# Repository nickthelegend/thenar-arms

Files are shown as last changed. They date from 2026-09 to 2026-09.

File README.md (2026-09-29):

# Thenar Arms

An original-derived SO-101 project with two separate builds: a six-MG996R
positional-servo **follower** and a passive, six-AS5600 **encoder leader**. The
repository includes converted STL parts, Bambu P1S geometry layouts, articulated
SolidWorks assemblies, a browser-based 3D viewer, an assembly animation, and
prototype ESP32 firmware.

> **Prototype status:** CAD and software checks are documented, but the complete
> printed mechanism, purchased hardware, wiring, and powered motion have **not**
> been physically validated. There is no payload rating or print-ready G-code.

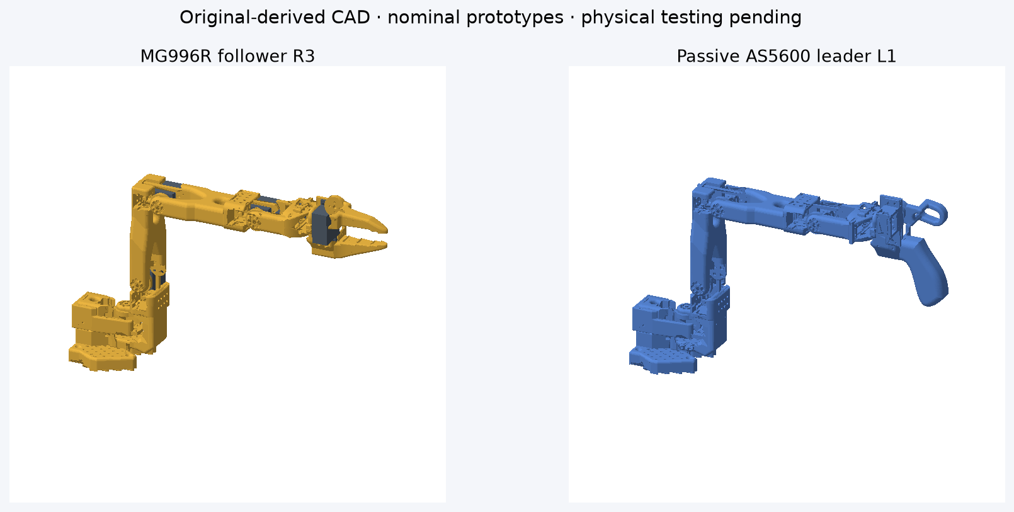
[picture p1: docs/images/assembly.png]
MG996R follower and encoder leader CAD assemblies


## Start here

| What you want | Link |
|---|---|
| Inspect both arms in 3D | [Open Robot Studio](https://nickthelegend.github.io/thenar-arms/) |
| See where each part goes | [Interactive 3D assembly film](https://nickthelegend.github.io/thenar-arms/assembly-video.html) — drag the timeline or pause at a step |
| Watch offline | [180-second MP4](robot-studio/public/video/thenar-real-3d-assembly-180s.mp4) |
| Build the MG996R follower | [Follower BOM, print notes and assembly](so101-mg996r/R3-PRINT.md) |
| Build the encoder leader | [Leader BOM, print notes, wiring and calibration](so101-mg996r/ENCODER-LEADER.md) |
| Use a Raspberry Pi 4B as host | [Pi 4B wiring and bridge guide](so101-mg996r/RASPBERRY-PI-4B.md) |
| Use only one ESP32 | [Pi-direct follower wiring guide](so101-mg996r/RASPBERRY-PI-DIRECT-FOLLOWER.md) and [large-print 90-second connection video](https://nickthelegend.github.io/thenar-arms/wiring-video.html) |

The one-ESP32 layout uses the ESP32 for leader sensing and Pi I²C for the
PCA9685. **The current bridge still needs a second ESP32**; a Pi-side follower
driver and physical electrical testing are not yet complete. The video is an
illustrated connector guide, not footage of the purchased boards.

The assembly animation uses project STL meshes and nominal CAD positions. Individual
fasteners and unspecified controller boards are not modeled. It is an assembly
guide, **not** proof that parts fit, move safely, or work electrically.

## Choose a build

| | MG996R follower R3 | Passive encoder leader L1 |
|---|---|---|
| Actuation / sensing | Six 180° positional MG996R servos; no external follower encoders | Six passive AS5600 angle-sensing joints; no drive servos |
| Print set | 7 joined units, 2 P1S geometry-only layouts | 37 pieces from 12 unique STLs, 3 P1S geometry-only layouts |
| Essential hardware | 6 matching 25T metal-disc horns, ESP32, PCA9685, separate regulated 6 V servo supply, mounting fasteners | 6 Adafruit 6357 AS5600 boards, 12 **688ZZ 8 × 16 × 5 mm** bearings, 6 diametric Ø6 × 2 mm magnets, ESP32, TCA9548A, fasteners |
| Files | [Follower STL/3MF ZIP](so101-mg996r/output/follower-r3/SO101-MG996R-R3-PROTOTYPE.zip) | [Leader STL/3MF/firmware ZIP](so101-mg996r/output/encoder-leader-l1/SO101-AS5600-LEADER-L1.zip) |
| Detailed guide | [R3-PRINT.md](so101-mg996r/R3-PRINT.md) | [ENCODER-LEADER.md](so101-mg996r/ENCODER-LEADER.md) |

These are **converted parts**, not the stock SO-101 Ender plates. Do not mix R3
follower brackets, L1 leader parts, earlier revisions, and untouched stock
parts. The original link shapes and source datums are retained; this is not a
whole-arm scale-up. Case, horn, bearing and board dimensions are nominal design
inputs, not measurements of the user's purchased components.

**Before a full print:** inspect every sliced layer in Bambu Studio, then
print and dry-fit one mount or one five-piece encoder cartridge. The 3MF files
are layouts, **not approved sliced projects**. The follower and leader guides
document unresolved slicer clipping/layer-review findings. PETG is the planned
structural material; a successful PLA test does not establish strength.

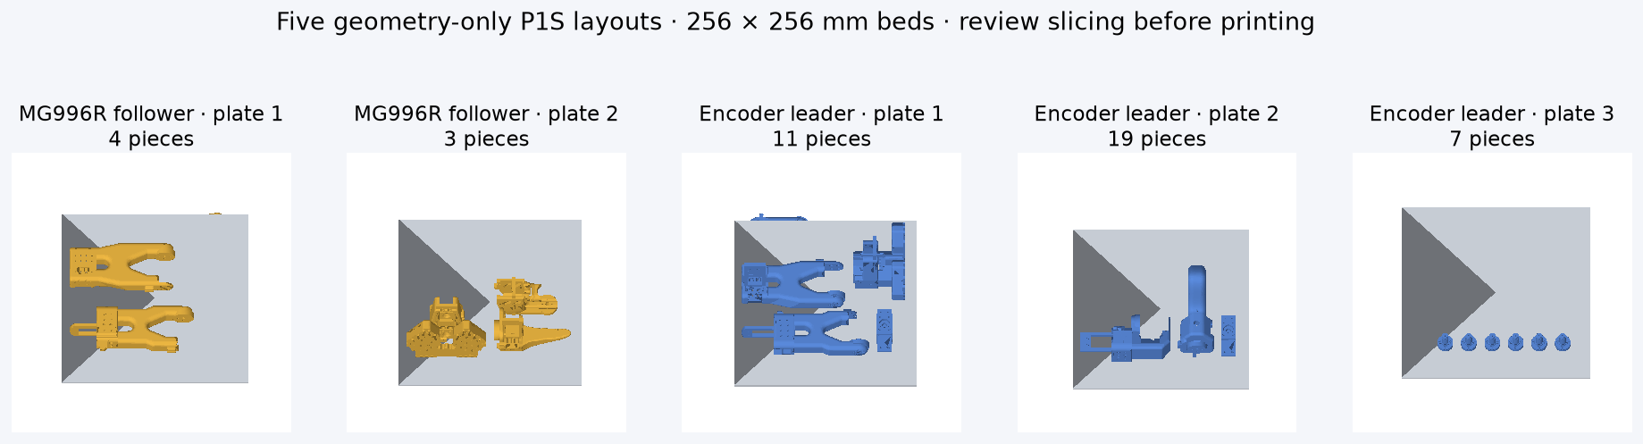
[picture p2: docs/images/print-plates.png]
P1S geometry layouts for the converted parts


## CAD, simulation and evidence

The [SolidWorks reconstruction release](https://github.com/nickthelegend/thenar-arms/releases/tag/solidworks-r3-l1-2026-09-23)
contains separate articulated follower and leader assemblies. Open the
[follower master](solidworks/assemblies/SO101_Follower_Master.SLDASM) or
[leader master](solidworks/assemblies/SO101_Leader_Master.SLDASM) with their
`solidworks/parts/` and `solidworks/hardware/` folders alongside them. See the
[SolidWorks guide](solidworks/README.md) and [reconstruction report](docs/final_report.md).

| Native assembly | Components | Moving joints | Recorded SolidWorks pose checks |
|---|---:|---:|---:|
| Follower R3 | 19 | 6, including jaw | 28/28 passed |
| Leader L1 | 73 | 6, including trigger | 28/28 passed |

The SolidWorks work did **not** modify the 330 existing project STL/3MF files;
those files do not need reprinting because of that reconstruction. Its CAD
solids are not byte-identical to the STLs. The reports document sampled surface
differences, a small leader-forearm solid-body separation, and collision
results. ROS 2 description and MuJoCo kinematics passed recorded pose checks;
ROS 2 visualization, Isaac import and physical dynamics were not tested.

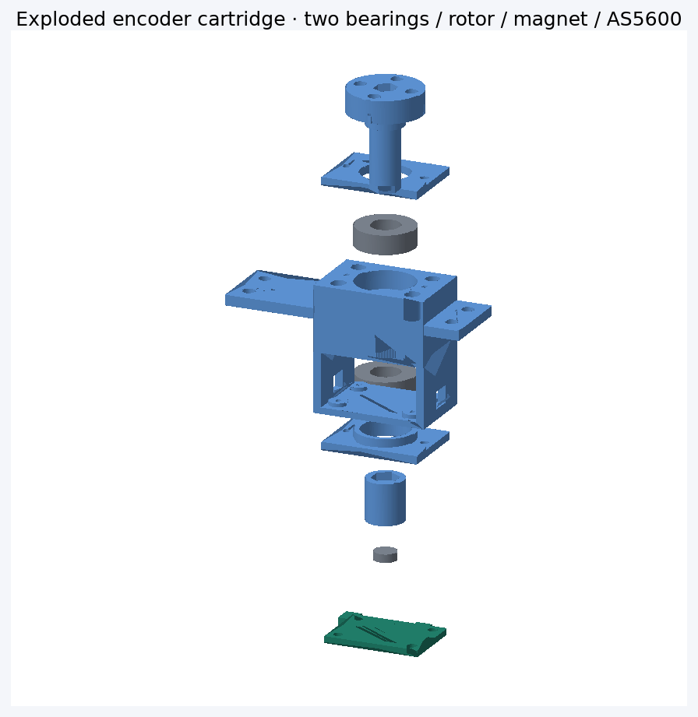
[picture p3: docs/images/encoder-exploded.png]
Exploded encoder cartridge CAD


### Validation boundaries

| Check | Recorded result |
|---|---|
| Closed single-shell print meshes | 7 follower + 12 unique leader meshes |
| Nominal mounting interfaces | 6/6 follower and 6/6 leader checks passed |
| Sampled internal collision poses | Follower 72/72 clear; leader 70/72 clear. Two folded leader collisions and table intersections remain documented. |
| Encoder cartridge | Sampled rotation/PCB checks show no positive overlap; magnet gap is nominally 2 mm. |
| P1S layouts | Five geometry layouts fit the P1S envelope with 12 mm part spacing. Slicing release is **not cleared**. |
| Firmware | Both ESP32 roles compile and host motion-math tests pass; follower stays locked until calibration. |
| Real hardware | **Not validated:** actual fits, bearings, sensors, wiring, strength, powered travel or payload. |

The browser preview checks discrete poses; it is not a swept-path or physical
safety certificate. The firmware STOP/OE path does not cut servo power. Clamp
and support the arm, and provide an accessible hardware power disconnect.
See the [encoder verification report](so101-mg996r/output/encoder-leader-l1/verification.json)
for machine-readable results.

## Run Robot Studio locally

```sh
cd robot-studio
npm ci
npm run dev
```

Open `http://127.0.0.1:5173/` for the arm viewer,
`http://127.0.0.1:5173/assembly-video.html` for the seekable 3D assembly
animation, or `http://127.0.0.1:5173/?geometry=clearance&view=fit-test` for
print-layout geometry. `?geometry=original` shows untouched upstream references.
The website does not connect to hardware.

<details>
<summary>Reproduce the current CAD and validation checks</summary>

Use a Python 3.12 environment with
[`so101-mg996r/requirements-cad.txt`](so101-mg996r/requirements-cad.txt)
installed, then run from the repository root:

```sh
python so101-mg996r/tools/build_encoder_leader.py
python so101-mg996r/tools/verify_encoder_leader.py
python so101-mg996r/tools/pack_encoder_leader.py
cd robot-studio
node scripts/verify-preview.mjs
node scripts/verify-r3.mjs
node scripts/verify-encoder.mjs
npm run build
```

Optional publishing/slicing scripts and firmware commands are in the kit
guides. No command here automatically flashes firmware or arms servos.

</details>

## Source and licences

The original SO-101 design is from
[TheRobotStudio/SO-ARM100](https://github.com/TheRobotStudio/SO-ARM100),
Apache-2.0; its licence is preserved at `so101-mg996r/source/LICENSE`.
The AS5600 board drawing is from
[Adafruit Industries](https://github.com/adafruit/Adafruit-AS5600-Magnetic-Angle-Sensor-PCB),
CC BY-SA, with attribution in `so101-mg996r/source/encoder/`.
Third-party assets keep their respective licences; this repository does not
relicense them. The images above are CAD renders, not photos of a tested robot.

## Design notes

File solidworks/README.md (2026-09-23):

# SolidWorks reconstruction

Engineering prototypes: not physically tested or payload rated. The existing R3 follower and L1 leader remain the geometric references; original CAD, print layouts, browser viewer and firmware were not redesigned.

Open `assemblies/SO101_Follower_Master.SLDASM` or `assemblies/SO101_Leader_Master.SLDASM` after their verification status is recorded in `../docs/final_report.md`. Keep the `parts/` and `hardware/` directories together with the assemblies so references resolve. Checkpoints and failed trials are retained separately and are not production substitutes.

The follower has 19 instances and six revolute joints, including the direct-drive moving jaw. The passive leader has 73 instances: 37 prints and 36 hardware envelopes, with six AS5600 sensing joints. Each assembly grounds only its base. Purchased envelopes, bearing caps and the source-surface patches use native features where practical. Most custom print geometry is retained as imported solid base features with native joint sketches, axes and planes; a fully editable manufacturing feature history has not been recovered.

## Move the joints

Use the ConfigurationManager to select **ZERO**, **HOME** or **MID_RANGE** for repeatable snapshots. These activate six optional pose-holding angle mates and suppress the redundant range mates. Select **FREE_MOTION** to suppress the holders and activate the six native Limit Angle mates, giving six bounded rotational freedoms. Select HOME before FREE_MOTION when you want to start from HOME. The named Mate Controller (`Follower_Joint_Poses` / `Leader_Joint_Poses`) operates the pose holders and stores individual minimum and maximum poses as well.

For scripted movement, use `tools/set_robot_pose.py follower 0 -25 35 0 0 20` (or `leader`) with the project Python environment. Add `--save` only to persist that pose. The task-local MCP tool `set_robot_joint_pose` accepts the same six logical degree values. It uses native mate solving, preserves all range properties and checks the resulting component transforms. Direct edits through the older API trial scripts can collapse limit bounds; use the supplied range-preserving helper.

In the Mates folder, `J1_Source_preview_limits` through `J6_Source_preview_limits` define the source ranges. `J1_Pose_driver` through `J6_Pose_driver` are the optional snapshot holders. They correspond to shoulder pan, shoulder lift, elbow flex, wrist flex, wrist roll and gripper/trigger. The native angle is **90 degrees + the logical joint angle**. Do not edit the configured minimum/maximum bounds when changing a pose. ZERO is [0,0,0,0,0,0]; HOME is [0,-25,35,0,0,20] degrees. MID_RANGE is [0,0,0,0,0,35].

API drag probes did not reliably preserve the entire follower assembly and were discarded. Free mouse dragging is unverified; use the configurations or native mate controls. The controlled pose tests do not certify collision-free physical movement. In particular, isolated J2_MAX and J3_MAX follower poses penetrate the tabletop.

## Geometry and frames

The source's native Z-up frame is retained. The viewer's side-by-side X placement is removed. The CAD scene includes the source +2.4 mm tabletop placement; the URDF robot base omits that scene placement. `simulation/cad_rig.json` records the explicit transformation. The `SOURCE_Z_UP` view changes only the camera, not robot coordinates.

The follower forearm has three solid partitions. The leader base and forearm each have four. The leader forearm requires a disclosed 0.00001 mm internal numerical separation. Source zero-thickness artifacts are retained as labelled native sheets on the leader trigger and forearm; no physical thickness is invented. These are geometric preservation choices, not physical manufacturing validation.

## Evidence and simulator handoffs

Read `../docs/final_report.md`, `../verification/original_vs_solidworks.md`, and the machine-readable evidence in `evidence/` and `../verification/`. The ROS 2 package is under `../ros2_ws/src/so101_description/`. MuJoCo and Isaac handoffs are under `../simulation/`.

Physical mass, center of mass, inertia, actuator/contact properties and calibration remain unverified. The MuJoCo structural template deliberately refuses to infer physical inertias. ROS 2 visualization and Isaac import have not been run in this environment.

The faceted CAD is memory intensive. Open one robot assembly at a time if memory is limited. Build tools checkpoint mates and clear their undo history; saved checkpoints provide recovery. The MCP bridge is task-local stdio tooling in `tools/solidworks_mcp.py`, with no network listener or persistent installation.

## Supported pose tools

Use `tools/set_robot_pose.py` or the MCP `set_robot_joint_pose` tool for normal movement. `validate_real_limits.py`, `verify_master_assembly.py` and `audit_native_mate_connections.py` are verification tools. Reconstruction and `probe_*` scripts include historical rejected trials; they are not normal movement commands. In particular, do not use `add_configuration_pose_drivers.py`, the old `validate_leader_motion.py`, or raw component-drag probes on the delivered masters.

The main report is `../docs/final_report.md`; `../verification/deliverable_files.json` indexes delivered files separately from checkpoints.

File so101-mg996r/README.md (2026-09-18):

# SO-101 original-geometry MG996R conversion work

## New: passive encoder leader L1

The original-derived leader conversion is now in `output/encoder-leader-l1`:
37 pieces on three P1S geometry layouts. See [ENCODER-LEADER.md](ENCODER-LEADER.md)
for the complete BOM, verified nominal interfaces, wiring, firmware and remaining
physical tests. The current viewer shows both converted assemblies. Full-plate
slicer clearance is still pending; these are not ready-to-run G-code files.

## Current: original-derived MG996R follower R3

The actual converted kit is now in `output/follower-r3/print-parts`: **seven
joined printing units**, derived from the original SO-101 parts. It has six
MG996R tab mounts, six metal-disc horn interfaces, joint-travel reliefs and an
8 mm local wrist extension. Use [R3-PRINT.md](R3-PRINT.md) for its current BOM,
dimensions and assembly notes. Do not mix R1/R2 parts or fasteners into this kit.

- Seven exported units are closed, positive-volume, single-shell meshes.
- All six nominal insertion and tab/horn screw-land checks pass.
- No internal overlaps above the report's threshold in 72 sampled poses;
  eight poses intersect the table and are guarded in the viewer.
- Two P1S geometry layouts hold all seven units with 12 mm part spacing.
- **Slicing review is still open:** both plates generated G-code, but clipping
  diagnostics and coarse toolpath-screen candidates remain. Ready-to-run sliced
  files are withheld. Full-plate printing is not approved by these checks.
- Physical fit, single-sided shaft support, strength, payload, cables and powered
  operation remain untested. Encoder leader L1 is supplied separately above.

The website defaults to this R3 follower. `?geometry=original` explicitly opens
the stock reference. `?geometry=clearance&view=fit-test` now shows the actual R3
layouts, not the earlier test-only or original SO-101 plates.

Download: [R3 prototype ZIP](output/follower-r3/SO101-MG996R-R3-PROTOTYPE.zip).
The sections below preserve earlier development results; they are **historical**
and do not describe the current R3 follower or its checks.

## Historical: printable MG996R bench-fit prototype R1

See [FIT-TEST.md](FIT-TEST.md) and [BOM.md](BOM.md). Actual original-derived
wrist-holder test STL/STEP and two small gauges are in `output/fit-test-r1`.
The holder adds mounting ledges, screw slots, nut access and an insertion opening.
It is one valid solid, with zero nominal servo overlap; all three test meshes
are watertight. This is separate from the incomplete full-arm study below.

P1S / 0.4 mm / PETG slicing passed: quick gauges approximately 18 minutes and
5 g; holder plus gauges approximately 1 hour 28 minutes and 24 g on one plate.
Print the quick gauges first. **Unpowered bench fit only; not a complete arm.**
The website's Print plates view now includes these test prints before the stock
SO-101 layouts. `?geometry=clearance&view=fit-test` opens them directly.

## Wrist-spacing development R2 — still not a print release

`output/wrist-spacing-r2` contains an editable original-derived wrist part with
an 8 mm local section extension. No global mesh scaling was used. With the roll
servo/gripper shifted accordingly, the two nominal wrist servo envelopes have
zero positive-volume interference in 81 pitch samples from -80° to +80° in 2°
steps; minimum sampled separation is approximately 2.566 mm. A 4 mm shift was
insufficient. This is a servo-pair test, NOT a complete assembly motion check.

The extension and clearance-cut STEP are each valid single solids, but the R2
STL still has open seams. An automatic repair was rejected because its volume
differed from the STEP by approximately 0.243%, exceeding the 0.1% repair gate.
R2 is intentionally not in the print-test ZIP or presented as printable. Flange,
horn, opposite-side support and surrounding-link checks remain incomplete.
The existing whole-arm report and viewer were not silently altered by this work.

## Historical initial study — NOT an MG996R print kit

All 14 requested individual STLs and both Ender combined layouts were downloaded
from TheRobotStudio/SO-ARM100 at commit
`eecbe3e0a9ebb23e25ad7b2759b03884c6660903`. They are byte-for-byte identical to
the same revision in the workspace. `source/provenance.json` records download
URLs, SHA-256 hashes, dimensions and mesh checks. Original files are unmodified.
The matching original STEP files are in `source/STEP`. Upstream Apache-2.0
licensing is preserved in `source/LICENSE`.

The website now renders these original shapes, not the earlier custom arm.
Follower joint frames come from the upstream URDF. The original leader handle
shares the wrist housing's mounting coordinates; its trigger pose is provisional.
Joint motion is a geometric preview, not a collision or hardware test.

## Historical initial verification and viewer update

The user has confirmed that the purchased servos only travel 180 degrees.
The MG996R preview now uses provisional ranges of ±85°, ±80°, ±80°, ±80°,
±85°, and 0–70° respectively. These are inspection limits, NOT mechanically
validated operating limits. The original-reference view retains upstream limits.
The two bases are separated by 800 mm for display only; no STL dimensions changed.

`output/motion-verification.json` records a 44-pose CAD check: home, neutral,
18 single-joint min/mid/max poses, 16 motion-demo samples and 8 seeded combined
poses. All 44 contain unresolved positive-volume overlaps in the nominal model.
There are seven home-pose candidates, including approximately 1,092 mm³ between
the unchanged wrist motor holder and the nominal MG996R envelope. Two draft
STLs still have open seams: Motor_holder_SO101_Base and Wrist_Roll_Pitch_SO101.
The check includes conservative circular horn envelopes, so the exact pair and
assumed hardware must be reviewed before deciding a repair. It does not certify
continuous swept motion, minimum clearance, leader encoders, strength or payload.

The website displays the report and lets you select its sampled poses. The
software tests verify that all twelve displayed joints move their attached
geometry, transforms remain finite, input is clamped, and the two display
assemblies do not overlap at home. These are software checks, not physical tests.

**Do not print the draft conversion as a finished arm.**

## Purchased servo — user-reported 180-degree travel

The user purchased a four-pack from
[Amazon ASIN B0F2TKPB95](https://www.amazon.in/dp/B0F2TKPB95).
The page was inspected on 2026-09-17. It identifies Generic / TESTIN ELECTRONICS,
not a verified TowerPro product. Its title advertises 180-degree operation, but
the description, included-components field and box contents describe a
360-degree continuous-rotation version. A verified buyer reports receiving
continuous-rotation servos. Those statements do NOT establish what the user
actually received; the page is internally inconsistent. The user's subsequent
confirmation of 180-degree travel is now recorded in `purchased-hardware.json`.

This distinction is essential: a positional servo accepts a target angle;
a continuous-rotation servo normally accepts speed/direction. Continuous-rotation
units cannot perform this arm's requested angle positioning without external
feedback or different servos. The user explicitly requested NO external arm
encoders, so adding them is not an approved workaround.

Before final calibration, test one servo off the robot with the horn
unloaded, using a servo tester and an appropriate separately powered supply.
Move the control slightly to either side of neutral: does the shaft move to a
new position and hold, or keep turning? Do not force the shaft by hand to test
travel. Do not power a servo from a microcontroller's GPIO or 3.3 V rail.
Stop if it stalls, overheats or behaves unexpectedly.

The listing's rounded 40 × 40 × 20 mm dimensions are not a machining drawing.
The supplied horn hole pattern, tab pitch and actual shaft datums remain
unmeasured. The fit study uses nominal MG996R geometry, NOT confirmed dimensions
of this Amazon product. Its nominal 20 mm metal horn is an assumption, not a
claim about the horn kits supplied with this purchase.

The follower needs six positional servos including the gripper. If only one
four-pack was purchased, two further matching units would eventually be needed;
confirm the existing units before buying any more.

## What was actually generated

- `source/Individual`: all 14 exact source STLs.
- `source/Follower` and `source/Leader`: both original Ender combined STLs.
- `source/STEP`: original editable solids, not reverse-engineered approximations.
- `output/manifest.json`: original-part assembly transforms for the viewer.
- `output/clearance-study`: localized subtractive fit-study STEP/STL exports,
  nominal MG996R reference mesh, and a per-part interference/removal report.

The fit study never scales or replaces the arm. It subtracts nominal servo,
horn and provisional cable-clearance envelopes at original joint locations.
It does NOT yet create a complete load-bearing attachment system. Some draft
tessellations have open seams; consult `fit-analysis.json`. These are inspection
artifacts, not print-ready parts. Watertightness alone would not establish
mechanical compatibility or strength.

The wrist motor holder clearance cut produces TWO separate solids and is
rejected. No converted wrist motor holder STL is exported. The wrist roll/pitch
part loses approximately 21.6% of its volume under the current assumptions,
which makes wall thickness and load paths especially important to review.

Four unaffected or leader-only files are preserved unchanged in the study
package. A draft suffix on them does not mean an encoder conversion was done.
The leader remains the original reference; AS5600 cartridges have not been
designed in this original-design branch.

## P1S layouts

The original Ender follower layout and original Ender leader layout each fit
inside a P1S 256 × 256 × 256 mm envelope after rigid translation only. Neither
the original orientations nor mesh scale is changed. Each layout occupies one
plate, with Y > 35 mm and X > 19 mm, clear of the front-left exclusion rectangle.
The website offers geometry-only 3MF layouts and the untouched combined STLs.

These are STOCK SO-101 plates, not MG996R plates. They are not sliced toolpaths.
No minimum-time claim, support approval, or MG996R print-time estimate is made.
Do not print them expecting the purchased MG996Rs to fit.

## Remaining engineering sequence

1. Calibrate the usable angle range and horn indexing of the reported 180-degree servos.
2. Measure body L/W/H, overall height, shaft offset, tab span/thickness/height,
   hole pitch and diameters, and the included horn hole pattern and stack height.
3. Register those measured datums to the original SO-101 joint axes.
4. Complete local tab mounts, horn attachment and opposite-side idler support;
   repair the rejected wrist mount while retaining the original design.
5. Check minimum walls, fastener access, cable bend paths and swept interference.
6. Evaluate direct-drive shoulder/elbow torque, current and heating. No payload
   is rated; published stall torque is not a continuous working torque.
7. Print and bench-test a single joint. Correct tolerances before full plates.
8. Fit passive encoder cartridges into the original leader housings.
9. Arrange only approved parts for P1S, slice, inspect supports and measure times.

The earlier `mg996r-arm` custom design and firmware are retained for history but
are NOT the authority for this requested original-design conversion. In
particular, its 2:1 transmission calibration must not be used for this branch.

## Reproduce

From the workspace root:

```sh
mg996r-arm/.venv/bin/python so101-mg996r/tools/import_sources.py
mg996r-arm/.venv/bin/python so101-mg996r/tools/clearance_study.py
mg996r-arm/.venv/bin/python so101-mg996r/tools/verify_motion.py
cd robot-studio
node scripts/verify-preview.mjs
npm run dev -- --host 127.0.0.1
```

The local site is normally at http://127.0.0.1:5173/.
Use its geometry selector for Original SO-101 versus MG996R clearance study.
Do not overwrite the source files with draft exports.

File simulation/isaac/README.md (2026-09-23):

# Isaac Sim import handoff

Import `source_urdf/so101.urdf` using the URDF importer in the installed Isaac Sim release. Relative mesh paths are self-contained. Follow `config/import_requirements.yaml`; compare the same joint vectors to `validation/canonical_pose_reference.json` in metres before accepting articulation.

Isaac Sim was unavailable in this task environment, so no import, USD or dynamics validation is claimed. `usd/` is intentionally empty. Missing physical inertials and unaccepted convex collision proxies block trustworthy physics. Do not accept automatic density, mass, drive gains or single-convex-hull approximations as measured robot data. Preserve the original dimensions and source joint limits.

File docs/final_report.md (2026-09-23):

# SO-101 SolidWorks reconstruction report

Engineering prototypes: **not physically tested or payload rated**. The current R3 six-MG996R follower and L1 passive six-AS5600 leader were reconstructed in SolidWorks 2026 SP4.1 through a task-local MCP bridge and the installed COM API. Original geometry, browser viewer, P1S layouts and firmware were preserved. All 330 original files match their saved hashes; see `verification/original_file_integrity.json`.

## Reconstruction

| Deliverable | Location | Instances / unique parts | Moving joints | Native mates / fixed components |
|---|---|---|---|---|
| Follower | `solidworks/assemblies/SO101_Follower_Master.SLDASM` | 19 / 9 | 5 arm + 1 jaw | 36 total; 30 active in FREE_MOTION / base only |
| Passive leader | `solidworks/assemblies/SO101_Leader_Master.SLDASM` | 73 / 18 | 5 arm + 1 trigger | 90 total; 84 active in FREE_MOTION / base only |

The leader comprises 37 printed instances and 36 hardware-envelope instances. Native feature hardware includes the MG996R envelope, metal horn, two bearing caps, PCB/chip/connectors, bearings and magnet. Custom printed geometry is mostly source-preserving imported solid base features with native datum sketches/axes/planes. This is **not** a recovered, fully parametric manufacturing feature history.

Final loaded references contain 11 follower solid bodies and 25 leader solid bodies across their unique parts. All return zero kernel faults. The leader additionally contains 11 healthy zero-thickness surface bodies preserving source artifacts. Native saved configuration checks pass with no reported mate errors. Only one root is grounded in each assembly.

Open one master at a time on a memory-limited workstation. Keep `solidworks/parts/` and `solidworks/hardware/` beside the assemblies. `solidworks/README.md` explains the controls and reference paths. Checkpoints and rejected trials are retained separately.

## Joint table

| Joint | Parent → child | Axis / positive sign | Zero; min…max (deg) | Servo channel / sensor mux | Motion |
|---|---|---|---|---|---|
| shoulder_pan | base_link → shoulder_link | local +Z / right-hand; default +1 | 0; -85…85 | 0 / 0 | Both CAD assemblies PASS |
| shoulder_lift | shoulder_link → upper_arm_link | local +Z / right-hand; default +1 | 0; -80…80 | 1 / 1 | Both CAD assemblies PASS |
| elbow_flex | upper_arm_link → lower_arm_link | local +Z / right-hand; default +1 | 0; -80…80 | 2 / 2 | Both CAD assemblies PASS |
| wrist_flex | lower_arm_link → wrist_link | local +Z / right-hand; default +1 | 0; -80…80 | 3 / 3 | Both CAD assemblies PASS |
| wrist_roll | wrist_link → gripper_link | local +Z / right-hand; default +1 | 0; -85…85 | 4 / 4 | Both CAD assemblies PASS |
| gripper | gripper_link → moving_jaw_so101_v1_link | local +Z / right-hand; default +1 | 0; 0…70 | 5 / 5 | Both CAD assemblies PASS |

Axes above are **local joint-frame +Z**, not all global vertical. Full measured origin XYZ/RPY and component mappings are in `simulation/joint_map.yaml` and `simulation/leader_joint_map.yaml`. Source frame: +X forward at HOME, +Y left, +Z up. Source viewer X separation is removed; CAD retains +2.4 mm tabletop placement. URDF base coordinates omit that scene placement; the explicit relation is in `simulation/cad_rig.json`.

ZERO = [0,0,0,0,0,0], HOME = [0,-25,35,0,0,20], MID_RANGE = [0,0,0,0,0,35] degrees. These are saved configurations. Native Mate Controllers also store 12 individual limit poses. Native mate angle = 90° + logical angle. The limits are **SOURCE VERIFIED software/preview bounds**, not measured safe mechanical stops. Do not command a physical robot merely because a pose is within these bounds.

The jaw and trigger are direct revolute DOFs; no additional coupled linkage was invented. Leader trigger mesh mounting index +15° is retained in its instance transform. Firmware leader ZERO capture is performed at HOME: q = home + sign × signed_wrap_12bit(raw − zero_counts) × 360/4096. Actual signs/count offsets and servo horn indexing remain UNVERIFIED.

## Accuracy

- **SOURCE VERIFIED:** source register and conflict decisions in `docs/source_audit.md`; modified R3/L1 geometry takes precedence over stock STEP files from a different revision. Detailed source dimensions, generator constants and original transforms were retained rather than averaged.
- **CAD MEASURED / CALCULATED:** follower printed surfaces compared using all vertices plus 30,000 samples per direction (50,000 for the partitioned forearm). Largest observed error: 0.001958407 mm. Base and wrist miss the stricter 0.001 mm trial, but all seven pass the source generator's 0.005 mm tolerance. This is sampled agreement, not mathematical identity.
- **CAD MEASURED / CALCULATED:** all 18 adopted leader part exports pass the recorded 0.005 mm surface, 0.001 mm bounds and per-type volume gates. Largest observed bidirectional surface discrepancy: 0.003381282 mm. Full values, stricter 1 µm outcomes and native-circle tessellation differences are in `verification/leader_geometry_comparison.json`.
- Follower forearm uses three valid solids in one rigid part. Leader base and forearm use four each. The leader forearm includes a disclosed 0.00001 mm internal numerical gap, approximately 0.0238 mm³ removed, to resolve coincident source facets rejected by the CAD kernel. Its zero-thickness source patch is preserved as eight surface facets; three trigger patches are likewise retained. No physical thickness was fabricated.
- Across 28 actual mate-solved poses, maximum follower component position/orientation difference is 2.66553607e-09 mm / 3.86653971e-10°. Leader maximum is 5.80356045e-07 mm / 3.86665823e-10°. Every component, including hardware, was compared to source forward kinematics.
- Hole/interface exteriors are included in the surface comparisons. Not every hole was reconstructed as an editable dimension. Unrepresented screws, cables and internal commercial-component details were not inferred into CAD.

## Motion validation

Every joint was exercised independently at minimum, zero, maximum and return; HOME and a combined pose were tested. Both assemblies pass all 28 recorded pose comparisons and the three saved-configuration reopen checks. Evidence is under `solidworks/evidence/`, plus `verification/follower_master_reopen.json`, `leader_master_reopen.json`, `joint_verification.csv` and `leader_joint_verification.csv`.

The final regression reads back all six genuine native Limit Angle feature types and their lower/upper bounds at every pose. Earlier fixed-angle and converted-mate trials are retained as superseded checkpoint evidence. The final limits were created with CreateMateData/CreateMate and explicit plane entities. Their current dimensions retain the default native driving state; making these dimensions driven caused the rejected bounds drift. Explicit joint-axis references prevent alternate angle solutions when configurations change. All six pose values are written explicitly per configuration, including unchanged values, to avoid stale inherited dimension state. Six separate optional angle holders make ZERO/HOME/MID_RANGE repeatable; these snapshots suppress the redundant range mates. FREE_MOTION suppresses the holders and activates all six limits. This avoids native redundant-mate warnings in the fixed snapshots. Only the base is fixed. Native component status with active limit mates is recorded separately and is not used as a numerical DOF count; suppression of a limit changes that diagnostic. The hinge graph and measured joint movement establish the reported articulation scope. Every native mate's actual component entities are audited against the source adjacency/rigid groups.

Constraint-matrix analysis gives six independent rotational freedoms and no additional infinitesimal freedoms at HOME for each native mate graph. This is **CALCULATED**, not a SolidWorks kernel DOF diagnostic or a mouse-drag test. Native mate-driven movement is separately CAD MEASURED.

Follower API drag probes and a leader direct-dimension solver-branch trial failed and were rejected. Saved masters were recovered/retested. Use named configurations and native mate controls; free mouse dragging remains UNVERIFIED. No accepted pose is produced by assigning arbitrary component transforms.

Discrete volumetric collision checks cover 15 named measured poses for each assembly (14 distinct joint vectors because J6_MIN equals ZERO), all component pairs, with no pair exclusion. Source zero-thickness leader sheets are retained in visual geometry but have no solid volume to intersect. Raw overlaps down to 0.00001 mm³ are recorded; 0.5 mm³ is the inherited source report threshold, not a physical clearance allowance. Follower native SolidWorks HOME interference independently confirms six intended servo shaft/horn engagements of about 9.032 mm³. No other follower sampled internal overlap exceeds 0.5 mm³; smaller fixed overlaps remain recorded.

- Follower `J2_MAX`: 10 components below table Z=0; lowest -193.784 mm.
- Follower `J3_MAX`: 3 components below table Z=0; lowest -73.187 mm.
- Leader `J2_MAX`: 37 components below table Z=0; lowest -203.582 mm.
- Leader `J3_MAX`: 9 components below table Z=0; lowest -82.985 mm.

The inherited L1 source report separately checks 72 poses, with two folded combined collision failures and 11 table-collision poses. Its cartridge checks cover 72 rotor samples, six interfaces and a source magnet-to-chip gap of 2 mm. Those are labelled source results; they are not substituted for current CAD measurements. Neither discrete set certifies swept motion, cables, physical fit or safe payload operation. Existing geometry was not redesigned to remove these limitations.

## Simulation and firmware

| Output | Status |
|---|---|
| `ros2_ws/src/so101_description/` | Xacro/XML, parser, connected tree (8 links/7 joints/6 moving), mesh paths/units and 28 pose regressions PASS. ROS 2 build/RViz not run; tooling was not found in the accessible environment. |
| `simulation/mujoco/so101_import_test.urdf` | MuJoCo 3.14.0 imports 6 joints; all 28 FK regressions PASS. Automatically inferred masses are explicitly rejected. No physical-dynamics stepping accepted. |
| `simulation/mujoco/so101.xml` | Structural MJCF template with inferred inertia disabled. Expected load rejection was tested. Requires real inertias and accepted contact geometry before dynamics. |
| `simulation/isaac/` | Self-contained validated URDF, meshes, importer requirements and pose references prepared. Isaac import/articulation/USD not tested; no USD fabricated. |
| `simulation/inertial_properties.yaml` | CAD unit-density geometric integrals and per-rigid-link contributions provided; physical mass, COM and inertia remain null/UNVERIFIED. |
| `so101-mg996r/firmware/joint_mapping.md` | Six PCA9685 channels 0–5 mapped to logical joints; ESP32 and leader AS5600/TCA9548A addresses, signs, HOME/zero and calibration relationships documented. Original firmware unchanged. |

Follower collision geometry uses source-envelope servo box/cylinder unions and exact CAD print/horn tessellation. Servo primitive union comparison passed (maximum sampled deviation 0.000324 mm). A fine convex print decomposition was rejected as impractically fragmented. Concave print meshes are retained for geometric inspection; validated convex dynamic-contact proxies are still outstanding. Simulators must not silently replace each concave print with one convex hull.

Firmware defaults are 1500 µs neutral, +1 sign, 5.555556 µs/degree, direct ratio 1:1. The 0.2° per 20 ms update ceiling is a 10°/s commanded slew, not a measured servo capability. No supported effort/payload rating is assigned.

## Unverified properties and next physical validation

1. Measure printed link/hardware masses, centers of mass and inertia or validate a defensible infill-aware model. Generic PETG, four walls and 25% gyroid do not justify uniform-solid mass. The plate filament total includes support/brim. Genuine TowerPro's 55 g reference is not confirmed for the user's generic units.
2. Check actual servo shaft/horn fit, bearing seats, fastener stack-ups, screw locations/retention and mounting tolerances. Some fasteners are listed in the source BOM but not spatially represented in the published assembly. Source zero-thickness patches and multipart seams need manufacturing review.
3. Measure mechanical stops and table/self-clearance over continuous motion, including cable routing and pinch regions. Software bounds are not verified physical limits.
4. Calibrate each servo neutral, sign, horn index, endpoint and backlash; each AS5600 zero count, direction, magnet alignment and usable sensing gap. Check the leader-to-follower mapping on a supported, power-limited prototype.
5. Measure torque/speed, friction, damping, compliance, contact behavior, power/current limits, thermal behavior and payload capacity. No values were invented to make a simulator run.
6. Validate free mouse dragging if desired. Named configurations and mate-definition controls are the tested CAD movement path.
7. Complete accepted convex contact proxies and run ROS 2 visualization, MuJoCo physical dynamics and Isaac articulation/USD validation when the required measured data/tooling are available.

## Evidence and reproducibility

The final task-local MCP command successfully set and saved HOME in both masters with all six native limits active and no mate errors. All 15 saved Mate Controller positions were then read back; see `solidworks/evidence/follower_mcp_pose_handoff.json`, `solidworks/evidence/leader_mcp_pose_handoff.json` and the two `*_final_controller_positions.json` files in that evidence directory. The follower is left open in its saved HOME configuration for handoff.

Five paired native SolidWorks and MuJoCo visual views (ZERO, J1_MAX, J2_MIN, MULTI and HOME) are in [the visual pose comparison](../verification/visual_pose_comparison.md). Their complete silhouettes and joint orientations were inspected after fitting each camera to its pose. Numerical component-transform regressions accompany the images; camera/shading differences are not treated as geometric errors.

`docs/source_audit.md`, `docs/decision_log.md`, `docs/open_issues.md`, `verification/original_vs_solidworks.md`, the two joint maps, raw pose/part evidence, and source hash manifest identify what is SOURCE VERIFIED, CAD MEASURED, CALCULATED or UNVERIFIED. The delivered-file index is `verification/deliverable_files.json`. Scripts are in `solidworks/tools/`; failed/rejected trials are explicitly separate from delivered masters. Do not rerun raw reconstruction scripts over accepted parts without first reading their checkpoint/adoption assumptions.

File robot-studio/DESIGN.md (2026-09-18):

# Robot inspection workspace

Mode: Operate. The user's instruction to build end to end settles the design workflow without a separate direction approval. Seven grounded directions considered: machining console, Onshape inspector, robotics lab notebook, precision product configurator, fabrication workbench, scientific instrument panel, museum exploded specimen. The fourth is the chosen direction: a light gray 3D inspection field, compact dark blue header, quiet component tree and precise joint controls. Amber identifies follower prints, blue identifies leader prints, graphite and metal identify purchased hardware. Measurements use tabular numerals. The CAD export is the visual centerpiece; there are no generated mock robot images. The cloud/quarry challengers do not serve an engineering inspection task; their whitespace discipline is retained. Mobile inspection preserves the viewport first and puts controls below it.

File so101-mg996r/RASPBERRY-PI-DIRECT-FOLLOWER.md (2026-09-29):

# One-ESP32 wiring: encoder leader → Pi 4B → MG996R follower

This is the **one-ESP32 alternative** requested for the Thenar arms. The ESP32 reads the six leader encoders; the Raspberry Pi 4B receives their data over USB and connects to the follower's PCA9685 PWM board over I²C. The PCA9685, **not six Pi GPIO pins**, generates the servo pulse channels.

```text
6 × AS5600 ── TCA9548A CH0–5 ── ESP32 (leader) ── USB data ── Pi 4B
                                                                 │ I²C-1
                                                                 ▼
                          6 × MG996R ◀── PCA9685 CH0–5 ◀── Pi GPIO header
                                  ▲              ▲
                                  └──── separate regulated 6 V, fuse/switch
```

This wiring has **not been physically tested** with the purchased boards. The current `firmware/bridge.py` speaks to a *second ESP32* on the follower; it does **not yet implement Pi-direct PCA9685 control**. Wiring this arrangement alone will not make the arm move. Keep the servo supply switched off until a Pi-side driver, calibration, and safety checks are ready.

## Connections, with power OFF

| From | To | Purpose |
| --- | --- | --- |
| ESP32 3V3 and GND | TCA9548A logic supply and GND; sensor 3V3 and GND | 3.3 V sensor bus; never servo power |
| ESP32 GPIO21 / GPIO22 | TCA9548A upstream SDA / SCL | Leader I²C |
| TCA9548A channels 0–5 SDA/SCL | One AS5600 SDA/SCL per channel | Six identical-address sensors (0x36) |
| ESP32 USB | Pi 4B USB-A port, **data-capable** cable | Leader serial data |
| Pi physical pin **1** (3V3) | PCA9685 **VCC** | Logic power only |
| Pi physical pin **6** (GND) | PCA9685 **GND** | Common logic/servo reference |
| Pi physical pin **3** (GPIO2 / SDA1) | PCA9685 **SDA** | I²C-1 data |
| Pi physical pin **5** (GPIO3 / SCL1) | PCA9685 **SCL** | I²C-1 clock |
| Pi physical pin **11** (GPIO17) | PCA9685 **OE**, if exposed | HIGH disables PWM; this is **not** an emergency stop |
| PCA9685 servo outputs 0–5 | MG996R signal leads, one per joint | Positional pulse signal |
| Separate regulated **6 V +** through fuse and accessible cut-off | PCA9685 **V+** / rated servo power distribution | Servo power, **not** Pi 5 V |
| Separate 6 V supply − | PCA9685 servo GND / common GND | Return path; shared with Pi logic GND |
| Pi 4B USB-C | Its own suitable 5 V / 3 A power supply | Pi power only |

On typical servo plugs, brown/black is ground, red is V+, and orange/yellow is signal, **but verify the markings and wiring of the servos you own**. The exact PCA9685 pin order, OE availability/default state, and power-terminal current rating vary by breakout. Follow the actual board silkscreen and seller documentation rather than the illustration in the video. Six MG996R motors can draw substantial peak current; select the 6 V supply, fuse, wire gauge, connectors, and distribution board from measured current and the purchased hardware ratings. Do not assume the PCA9685 board's copper traces can distribute any arbitrary current.

The PCA9685 **VCC** is 3.3 V logic; **V+** is the separate servo supply. Their grounds must share a reference, but their positive rails must **never** be tied together. Use a physical cut-off in the 6 V rail. OE can default to enabled on some boards, and software can crash or retain the last commanded pulse. Keep servo power off during boot and setup; confirm OE behavior on your actual board before relying on it.

## Bring-up order

1. With the 6 V servo rail **off**, verify every wire against the table and check for shorts/polarity errors.
2. Power the Pi from USB-C and the leader ESP32 from Pi USB. Run the existing leader-only monitor mode; confirm six stable encoder readings.
3. Enable Pi I²C-1 and confirm that the PCA9685 responds at its expected address (usually `0x40`) before any servo is plugged in.
4. Implement and bench-test a Pi-side PCA9685 follower driver with a disabled-by-default output, stale-leader timeout, home-pose check, per-joint calibrated pulse limits, and a manual disarm path. The current two-ESP32 bridge cannot do this step.
5. Support the follower and connect **one unloaded servo**. Establish its safe centre, direction, mechanical limits, and supply behavior before trying the remaining five.

Sources: [Raspberry Pi 4B GPIO and power documentation](https://www.raspberrypi.com/documentation/computers/raspberry-pi.html), [Adafruit PCA9685 pin/power explanation](https://learn.adafruit.com/16-channel-pwm-servo-driver?view=all), [Adafruit Pi-to-PCA9685 wiring example](https://learn.adafruit.com/adafruit-16-channel-servo-driver-with-raspberry-pi/hooking-it-up). This is a nominal wiring plan, not a certification or physical validation report.

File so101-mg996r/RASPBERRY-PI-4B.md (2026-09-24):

# Raspberry Pi 4B host for the Thenar leader + follower

The Pi 4B runs `firmware/bridge.py`; it **does not drive the six MG996R servos directly**. Use one USB-connected ESP32 for the passive encoder leader and a second USB-connected ESP32 for the powered follower.

```text
6 × AS5600 → TCA9548A channels 0–5 → leader ESP32 ── USB 1 ──┐
                                                            Raspberry Pi 4B
6 × MG996R ← PCA9685 channels 0–5 ← follower ESP32 ─ USB 2 ──┘
      ↑               ↑
      └── separate regulated 6 V servo supply; common GND ──────┘
```

## Wiring essentials

| Item | Connect |
| --- | --- |
| Pi 4B power | Its own 5 V / 3 A USB-C supply, per [Raspberry Pi's guidance](https://www.raspberrypi.com/documentation/computers/getting-started.html) |
| Leader ESP32 | Pi USB port; ESP32 GPIO21 SDA and GPIO22 SCL to TCA9548A upstream; 3.3 V logic; AS5600 sensors each on separate mux channels 0–5 |
| Follower ESP32 | Second Pi USB port; GPIO21 SDA and GPIO22 SCL to PCA9685; GPIO25 to PCA9685 OE, with a 10 kΩ pull-up from OE to 3.3 V |
| Servo signal | PCA9685 channels 0–5 to the six MG996R signal leads |
| Servo power | Separate regulated 6 V supply to PCA9685 servo V+ and GND; **not** Pi 5 V, USB, or ESP32 3.3 V |
| Ground | Tie follower servo-supply GND to PCA9685 and follower ESP32 GND; verify polarity before power |

The 6 V / 10–15 A range in [R3-PRINT.md](R3-PRINT.md) is a planning range, **not** a measured current specification for your purchased servos. Size the supply and wiring after measuring loaded/stall current, and add a means of disconnecting servo power. [Adafruit's PCA9685 guidance](https://learn.adafruit.com/16-channel-pwm-servo-driver?view=all) also separates logic power and external servo power.

## Run on Raspberry Pi OS

The Pi needs Raspberry Pi OS, Python 3, two USB data cables, `numpy`, and `pyserial`. From the repository directory on the Pi:

```bash
python3 -m venv --system-site-packages .venv
.venv/bin/pip install numpy pyserial
ls -l /dev/serial/by-id/
```

Use the two stable `/dev/serial/by-id/...` device names shown by that last command, if available. They must point to *different* ESP32 boards. If the directory is empty, inspect `ls /dev/ttyUSB* /dev/ttyACM*` after connecting each board one at a time. For a Linux serial permission error, add your user to the `dialout` group and log in again.

Start with **leader-only monitor mode**, which sends no follower motion:

```bash
.venv/bin/python so101-mg996r/firmware/bridge.py --leader /dev/serial/by-id/YOUR_LEADER_ID
```

The leader firmware should emit six angles in lines beginning `L`. Only after dry-fitting the printed links, confirming magnet readings, centering all six servos, testing power/GND, calibrating horn orientation and physical travel, and supporting the follower at home should you connect the follower and opt into arming:

```bash
.venv/bin/python so101-mg996r/firmware/bridge.py --leader /dev/serial/by-id/YOUR_LEADER_ID --follower /dev/serial/by-id/YOUR_FOLLOWER_ID --arm
```

The bridge opens both serial links at 115200 baud and attempts a STOP handshake before arming. Its software angle limits and tabletop guard are not a substitute for measured hard-stop limits, current protection, or an accessible power cutoff. The MG996R model is a **180° positional servo**, so do not command motion beyond its calibrated physical range. The repository's leader/follower firmware source still needs to be flashed to the respective ESP32s; this guide does not claim that electronics or the printed mechanism have been physically validated.

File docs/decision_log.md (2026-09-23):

# Reconstruction decisions

The accepted result is summarized in final_report.md. Raw accepted and rejected evidence is retained in solidworks/evidence, solidworks/checkpoints and verification.

1. Preserve current R3 follower and L1 leader revisions. Upstream STEP files describe a different revision and were not substituted. Current generator dimensions, meshes and assembly transforms define the modified geometry. All 330 original files match their saved hashes.
2. Use the running SolidWorks 2026 SP4.1 COM API through a task-local stdio MCP bridge. No permanent plugin or network listener was installed. Native parts, assemblies, datums and mate features are saved on disk.
3. Preserve the unrelated SolidWorks_Test_Plate.SLDPRT. It had no unsaved edits before memory-exhausted application recovery and was reopened unchanged. Incremental mate saves and cleared undo history enabled the large faceted leader build to recover from checkpoints.
4. Rebuild simple hardware with native sketches/extrusions/cuts. Preserve complex modified prints as solid base geometry with native joint datums rather than claiming recovered manufacturing feature histories. Disable sketch inference and verify datum endpoints numerically.
5. Use explicit COM VT_ARRAY|VT_R8 transform arrays and assert readback: plain Python lists silently produced identity. Convert source intrinsic XYZ rotations and URDF extrinsic xyz RPY explicitly. SOURCE_Z_UP changes the camera only; source native coordinates are preserved.
6. Reject automatic repairs that materially alter surfaces, even if volume is nearly unchanged. Accept partitioned CAD only after kernel, volume, bounds and bidirectional exterior checks. The follower forearm has three solid partitions; leader base and forearm each have four. The leader forearm requires a disclosed 0.00001 mm internal separation at Z=16.2 mm.
7. Preserve source zero-thickness artifacts. Omitting trigger flaps caused about 0.967 mm surface error despite negligible volume change and was rejected. Three trigger sheets and eight forearm surface facets preserve them without invented thickness. They are excluded only from volumetric collision calculations.
8. Ground only each base. Lock hardware to its source rigid group. Each joint uses axis-collinearity, axial-plane and limit-angle mates. Native angle equals 90 degrees plus logical angle. Source software limits remain labelled separately from unknown physical safe limits.
9. Accept motion only after native mate solving and measured component-transform comparisons. Follower API drag probes and a leader direct-dimension branch trial failed and were rejected. Recover saved assemblies and use mate-definition changes for accepted motion. Independently read back stored configurations; failed trials do not count as passes.
10. A six-DOF constraint-matrix result is CALCULATED from native mate topology and measured frames, not a SolidWorks kernel DOF or mouse-drag diagnostic. Discrete collision checks are not swept-motion certification. Report intentional shaft/horn engagements and small overlaps instead of silently excluding pairs.
11. Preserve original workspace collisions. Some source-valid angle commands penetrate the table. The inherited leader 72-pose report and current CAD results remain separate evidence; do not redesign geometry to remove their limitations.
12. Do not fabricate physical mass/COM/inertia, effort, friction, damping, armature or contact parameters. Unit-density CAD integrals are geometric preparation. PETG/25% gyroid/four-wall print settings and a plate total cannot supply link mass. A genuine TowerPro 55 g reference is not automatically applicable to generic MG996R units.
13. Compare Xacro/URDF and MuJoCo forward kinematics with the same 28 canonical joint vectors. Reject importer-inferred masses. The dedicated MJCF disables inferred inertia and deliberately rejects physical-model loading until supported inertias exist. ROS 2/RViz and Isaac were not found in the accessible runtime; prepare handoffs without claiming execution or fabricating USD.
14. Verify source-envelope box/cylinder unions for servo collision geometry. Retain exact concave print/horn meshes for geometric inspection. Fine convex decomposition was impractically fragmented and was not accepted. Validated dynamic-contact print proxies remain outstanding.

## Final range-mate correction

The delivered-mate readback gate caught that editing IAngleMateFeatureData.Angle in SolidWorks 2026 collapses its lower/upper bounds to the current angle unless the range properties are reapplied. Earlier fixed-angle pose tests established kinematics but did not establish free rotational mobility. Those files are checkpointed as fixed-angle pose evidence and superseded by the range-mate regression.

A subsequent saved-configuration test rejected that intermediate conversion workflow: marking the limit dimension driven allowed its bounds to shift during movement. The accepted construction creates fresh IAngleMateFeatureData through CreateMateData/CreateMate, provides the two datum-plane entities explicitly, and verifies the native MateLimitPlanarAngleDim feature type. Its default driving dimension state is retained. Six separate standard angle holders position the joints and store the named configurations; they are suppressed in FREE_MOTION. Moving the holders then leaves the actual range bounds unchanged. Reacquiring COM objects after feature modification remains necessary. Final acceptance requires every component transform, min/max readback, configuration round trips and independent saved-file reopen checks.

Use real_limit_mates.py, validate_real_limits.py or set_robot_pose.py for future pose work. Legacy fixed-angle or drag trial scripts are retained for traceability and must not be used over a delivered master. The task-local MCP bridge now exposes set_robot_joint_pose with source-bound validation and post-solve checks. No original geometry was changed by this correction.

API reference: https://help.solidworks.com/2026/English/api/sldworksapi/SolidWorks.Interop.sldworks~SolidWorks.Interop.sldworks.IAngleMateFeatureData~IsAdvancedMate.html . Driven mate UI reference: https://help.solidworks.com/2026/english/SolidWorks/Sldworks/t_assembly_mate_controller_drag_position.htm .

Explicit parent joint-axis references prevent ambiguous angle solutions during configuration changes. Standard snapshot angle holders and active range mates can produce redundant-mate warnings together, so snapshot configurations activate the holders and suppress ranges; FREE_MOTION activates ranges and suppresses holders. Every canonical motion regression is measured after the holders are released and all six native ranges are active.

The expected native status-2 gate was rejected as an inappropriate DOF test: with a genuine Limit Angle active, GetConstrainedStatus returned 3; suppressing that range alone returned 2, restoring it returned 3. We record this observation without treating the component-status enum as a DOF count. Full-range mate-solved movement, exact active mate/entity topology and the calculated constraint nullspace are the articulation checks. API drag attempts remain rejected; mouse dragging is explicitly unverified.

For the follower's inherited angle dimensions, a stored numeric value could match the requested value while the current configuration remained on an alternate geometric solution. The supported helper now writes all six values explicitly into the active named configuration rather than skipping apparently unchanged dimensions. Explicit axis references then resolve the wrist/jaw branches; all final acceptance poses are measured afterward. No arbitrary component transforms are assigned to obtain accepted poses.

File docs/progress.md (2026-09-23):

# Reconstruction status

The delivered SolidWorks masters, geometry comparisons, native mate-driven motion, saved configurations, firmware mappings and available kinematic simulation checks are complete. Quantitative results and limitations are in `final_report.md`.

- Source audit: 330 original files inspected and hash-preserved; R3 follower and L1 leader revisions retained.
- Follower: 19 instances, nine unique parts, one fixed base, 36 total mates (30 active in FREE_MOTION) and six revolute DOFs.
- Leader: 73 instances, 18 unique parts, one fixed base, 90 total mates (84 active in FREE_MOTION) and six passive revolute DOFs.
- Both assemblies: 28 native mate-driven pose checks, three stored-configuration reopen checks, six-DOF constraint-rank calculation and 15 discrete all-pair collision checks completed. Existing table/collision limitations remain documented.
- Geometry: native hardware features where practical; imported solid base geometry with native joint datums for complex prints. Source seams and zero-thickness artifacts are disclosed. No recovered full parametric print history is claimed.
- ROS description: Xacro/parser/tree/units/paths and 28-pose regressions pass. MuJoCo URDF-import kinematics pass the same poses. Visual comparisons are recorded separately.
- Physical mass, COM, inertia, actuator/contact properties, calibration, payload and continuous clearances remain UNVERIFIED. Concave prints still need accepted dynamic contact proxies. The MJCF structural template intentionally does not run physical dynamics without real inertias.
- ROS 2/RViz and Isaac import/USD were not run in this environment. Their assets and requirements are prepared; no successful runtime claim is made.
- Free mouse dragging is unverified. Native mate controls and named configurations are the tested movement path.

Engineering prototypes: not physically tested or payload rated. See `open_issues.md` for the outstanding physical/tooling requirements.

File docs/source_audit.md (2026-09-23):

# Reconstruction source audit

Current target: SO101-MG996R follower R3 and passive AS5600 leader L1. Engineering prototypes, not physically tested or payload rated.

## Authority and revision

No original parametric CAD, SLDPRT, SLDASM or FCStd is present in the supplied project. Fourteen upstream STEP solids exist, but these are the STOCK geometry. The current R3/L1 modifications were performed on the upstream STL meshes with manifold3d, not on those STEP solids. Substituting stock STEP geometry would discard current mounts, travel reliefs, seam overlaps and wrist extensions. The R3/L1 generator code plus its hash-identified released meshes and assembly transforms are the authority for the CURRENT revisions. Historical R1/R2/clearance STEP files are not current R3 parts. No geometry averaging is permitted.

The audit inventories and hashes every original file, reads text sources into a searchable line index, inventories ZIP/3MF contents, and measures every used published mesh. Binary source files are preserved. These checks do not establish native feature reconstruction or physical fit. See verification/source_geometry.json and solidworks/checkpoints/original_files_sha256.json.

## Dimensional register

| Quantity | Value | Units | Source | Classification / conflicts |
|---|---|---|---|---|
| MG996R case | 40.9 × 20 × 37 | mm | R3-PRINT.md; build_follower_r3.servo | SOURCE VERIFIED nominal input; purchased hardware unmeasured |
| Case bottom / top | -28.5 / 8.5 | mm local servo Z | build_follower_r3.servo | SOURCE VERIFIED |
| Shaft centre | 12.5, 0 | mm local servo XY | build_follower_r3.cyl | SOURCE VERIFIED |
| Shaft tip | 14.2 | mm local servo Z | build_follower_r3.servo | SOURCE VERIFIED; historical clearance model differs |
| Tab span / width / thickness | 54 / 20 / 2.6 | mm | build_follower_r3.servo | SOURCE VERIFIED nominal |
| Tab holes / slots | 49.5 × 10 / 5 × 3.4 | mm | R3-PRINT.md; slots() | SOURCE VERIFIED nominal |
| Metal disc / hole PCD | 20 / 14 | mm | metal_horn() | SOURCE VERIFIED option, actual horn UNVERIFIED |
| Metal-disc holes | 2.5 | mm | metal_horn() | SOURCE VERIFIED tap-drill envelope; M3 threads unmodelled |
| Printed horn holes / centre bore | 3.4 / 6.4 | mm | horn_plate() | SOURCE VERIFIED |
| Horn stack / driven plate | 4.5 / 6 | mm | metal_horn(); horn_plate() | SOURCE VERIFIED |
| Follower wrist extension | 8 | mm | R3 generator + manifests | SOURCE VERIFIED; do not use stock/R2 geometry |
| Leader wrist extension | 14 | mm | L1 generator | SOURCE VERIFIED; differs deliberately from follower |
| Shoulder seam overlap | 0.031, -0.047, 0.029 | mm | R3 generator | SOURCE VERIFIED local translation |
| Follower forearm seam overlap | 0, -0.05, 0 | mm | R3 generator | SOURCE VERIFIED local translation |
| Adafruit6357 board | 25.4 × 17.78 × 1.6 | mm | Eagle + L1 source | Outline SOURCE VERIFIED; thickness ASSUMED in source |
| PCB holes | ±10.16 × ±6.35; diameter 2.5 | mm | Eagle + L1 source | SOURCE VERIFIED |
| Bearings | 8 × 16 × 5 | mm | ENCODER-LEADER.md; L1 source | SOURCE VERIFIED nominal 688ZZ |
| Bearing pocket / journal | 16.3 / 7.95 | mm | cartridge_parts() | SOURCE VERIFIED |
| Magnet / pocket | diameter 6 × 2 / diameter 6.2 | mm | cartridge_parts() | SOURCE VERIFIED nominal |
| Magnet-to-chip gap | 2 | mm | L1 report + source | SOURCE VERIFIED nominal; field strength UNVERIFIED |
| Leader trigger indexing | +15 | deg | L1 context() | SOURCE VERIFIED revision correction |
| Follower joint origins | six complete matrices | mm / degrees | published manifest | SOURCE VERIFIED; copied to simulation/joint_map.yaml in SI |
| Home | 0, -25, 35, 0, 0, 20 | deg | model.h + manifest | SOURCE VERIFIED; differs from ZERO |
| Preview/command limits | ±85, ±80, ±80, ±80, ±85, 0–70 | deg | model.h + manifest | SOURCE VERIFIED software limits, NOT physical travel certification |
| Direct drive ratio | 1:1 | ratio | model.h + R3 guide | SOURCE VERIFIED; historical custom-arm 2:1 is excluded |
| Display base separation | 800 | mm | publisher/viewer | Display only; remove ±400 mm X shifts for separate robot assemblies |

## Coordinates and mechanism

Source position values are millimetres; source rotations use intrinsic XYZ Euler degrees (Three.js XYZ). Each fixed joint datum is followed by an independent local Z rotation. Converting these rotations to URDF requires matrix conversion to extrinsic xyz RPY radians, not copying the Euler triples. Native SolidWorks assembly convention will retain source world axes with Z up. Separate assemblies remove only viewer root X offsets; the 2.4 mm vertical root placement is explicit. ROS base_link convention retains original URDF frame and needs an explicit ground offset of 2.4 mm when used with a table.

The sixth follower actuator rotates one moving jaw directly; the opposite gripping surface is part of Gripper_body. There is no evidence of a paired-jaw linkage, gear reduction, or parallel-jaw translation. Horns belong to child links, servo bodies to parent links. Leader rotor, magnet cup and magnet belong to child links; cartridge, caps, boards and bearing envelopes belong to parent links.

## Conflicts and unknowns

The original URDF includes STS3215 mass/inertia and limits. They cannot be reused for the modified MG996R/PETG robot. Physical servo signs, horn indexing, travel and pulse slopes are uncalibrated defaults. Materials/infill and purchased component masses do not establish assembled mass/inertia. Keep unknown dynamics UNVERIFIED.

Existing follower report: 72 discrete poses internally clear at its 0.5 mm³ threshold, eight table-intersection poses. Existing leader report: two folded internal collisions, eleven table-intersection poses. These are inherited source reports, not new SolidWorks tests, and they do not certify swept motion. Preserve known collisions without redesigning geometry.

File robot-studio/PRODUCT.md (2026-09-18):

# Thenar robot studio

An engineering viewer for the workspace owner's MG996R follower and magnetic-encoder leader. The user explicitly asked to build both robots, inspect the actual 3D assemblies in a website, verify the design, export printable components and arrange them efficiently for a Bambu P1S. Success means rotating actual exported meshes, exercising matching joint poses, inspecting purchased components separately from printable parts, and downloading CAD and arranged plates. The current prototype is physically untested; reports must distinguish geometric checks from physical fit and motion validation. No hardware control is exposed in the website. Chosen implementation assumptions: daylight engineering workspace, desktop-first with responsive mobile controls, local CAD exports as authoritative assets, dark blue structure and amber follower parts with blue leader parts. These choices implement the user's request to proceed end to end.

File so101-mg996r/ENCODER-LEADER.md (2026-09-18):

# SO-101 passive AS5600 encoder leader · L1

**Nominal assembly prototype, not physically validated.** This kit converts the
original SO-101 leader links, handle and trigger to six passive encoder joints.
It does not put encoders on the MG996R follower. Do not use stock SO-101 plates
or mix L1 leader parts with R3 follower brackets.

## Files and plates

`output/encoder-leader-l1/print-parts/` contains seven main printing units:
Base, Shoulder, Upper_arm, Forearm, Wrist_pitch_roll, Handle and Trigger,
all ending `_Encoder_L1.stl`. Print one each.

Print **six each** of `Encoder_cartridge_L1`, `Bearing_cap_front_L1`,
`Bearing_cap_rear_L1`, `Encoder_rotor_L1`, and `Magnet_cup_L1`.
Total: **37 pieces, 12 unique files, three P1S geometry-only 3MF layouts**.
The MG996R follower adds seven pieces on two plates: five layouts for both.
Only files listed in the reports/ZIP are kit parts; engineering intermediates
and diagnostic candidates are not alternate print files.

Packing tries 16 rectangle-packing variants, with 12 mm part spacing, a 35 mm
front reserve and 5 mm outer clearance. This is not a proven minimum print time.
Starting settings: P1S, 0.4 mm nozzle, PETG, 0.20 mm layers, four walls, 25%
gyroid, automatic supports and 5 mm outer brim, printing by layer.
**Geometry layouts are not print-approved G-code.** Inspect all sliced layers,
especially bearing shoulders, rotor pockets and support removal. See
`plate-report.json` for actual slicer results. Full-plate release is withheld
while slicer clipping diagnostics/layer review remain unresolved.

Start with ONE five-piece cartridge set, not the complete plates.
Use the separate `test-first/P1S_ENCODER_CARTRIDGE_FIT.3mf` in the ZIP for this;
it is an optional preliminary print, not a fourth full-kit leader plate.
This test layout sliced without logged errors: estimated 1h19m, 25.41 g PETG.
Full leader layouts estimate 27h34m and 671.04 g, including supports/brims with
the recorded settings; plates1–2 log clipping errors. Estimates are not measured
print times or permission to skip layer inspection.
Keep support
scars out of the bearing seats. Check the 7.95 mm journal and 16.3 mm bearing
pocket with your printer/material. Sand lightly if needed; never force bearings
into brittle or undersized prints. Reject cracked or loose load-bearing parts.

## Complete incremental leader BOM

| Item | Qty | Required specification |
|---|---:|---|
| AS5600 breakout | 6 | **Adafruit 6357** geometry; generic AS5600 boards are not interchangeable |
| Bearings | 12 | **688ZZ, 8 × 16 × 5 mm**; not the 4 mm-wide open bearing variant |
| Magnets | 6 | Ø6 × 2 mm, **diametrically** magnetized; axial magnets will not work |
| Main printed units | 7 | One of each original-derived L1 unit |
| Cartridge printed pieces | 30 | Six of each of the five reusable parts |
| Cartridge mounting bolts | 24 | M3 × 12, four per joint |
| Rotor-to-link bolts | 24 | M3 × 12, four on Ø14 mm PCD per joint |
| Axle retainers | 6 | M3 × 35 countersunk; verify actual head size and protrusion |
| M3 nuts | 54 | 24 mounting + 24 rotor + 6 axle; standard 5.5 mm AF |
| M3 washers | 48 | Approximately Ø7 mm, both sides of mounting tabs |
| Bearing cap screws | 24 | M2 × 6, into printed pilot holes, do not over-tighten |
| PCB screws | 24 | M2 × 4, into printed pilots; verify engagement without crushing PCB |
| ESP32 development board | 1 | Classic ESP32 target, USB cable ×1 |
| TCA9548A breakout | 1 | Address 0x70, logic and pull-ups at 3.3 V |
| Flexible sensor leads | 6 sets | Four conductors each; strain relief/service loops at every axis |
| Desk clamps | 2 | Suit original base and your desk |
| Magnet adhesive | as needed | Retain magnet in cup; keep adhesive out of bearings |

Use an additional ESP32/PCA9685 for the follower: see [R3-PRINT.md](R3-PRINT.md).
Add a **10 kΩ pull-up from PCA9685 OE to 3.3 V**, connect OE to follower GPIO25.
A hardware servo-power disconnect, suitable regulated servo supply, common
ground and wiring/fusing sized for the actual motors are required. Do not power
six servos from USB or the ESP32. No final current/load rating is established.
No electronics enclosure or exact ESP32/mux/PCA board mounting model is supplied:
those board variants have not been selected. Reference meshes are not electronics
to print. Only the AS5600 board is geometrically specified.

## Dimensions and retained design

The original SO-101 link geometry is locally cut/extended, not globally scaled.
The leader wrist is extended 14 mm. Handle and its fixed wrist bracket are joined.
The trigger mounting face is corrected and indexed +15° to avoid its original
misregistered position. Tiny documented seam overlaps join tangent source meshes.

| Interface | Nominal CAD value |
|---|---|
| AS5600 board | 25.4 × 17.78 mm; 1.6 mm thickness assumed |
| Four PCB hole centres | ±10.16 × ±6.35 mm from sensor centre; holes Ø2.5 |
| Bearing pockets / journal | Ø16.3 / Ø7.95 mm |
| Cartridge tab span / thickness | 64 / 2.6 mm |
| Four cartridge holes | 55.5 × 10 mm spacing; Ø3.4 |
| Printed rotor disc | Ø20 mm; four M3 holes on Ø14 PCD |
| Magnet pocket | Ø6.2 mm, adhesive retained |
| Magnet bottom to chip top | 2.0 mm nominal; field strength must be tested |
| Output travel limit | ±85°, ±80°, ±80°, ±80°, ±85°, 0–70° |
| Calibration home | 0°, −25°, +35°, 0°, 0°, +20° |

The cartridge is a printed shaft/journal design reinforced by an axial M3
retainer, not a machined precision shaft. Bearing preload, play and durability
are bench-test questions. The reference PCB includes conservative connector
envelopes, not every solder fillet/component height.

## Assembly order (unpowered)

1. Print one cartridge set. Trial-fit both bearings and cap screws. Clean the
   through-bores; check the rotor turns freely without caps rubbing it.
2. Slide the AS5600 PCB into the lower frame, component side toward the magnet.
   Attach its four M2 screws. Fit leads through side openings before closing it.
3. Fit the rear bearing and rear cap, then the front bearing. Insert the rotor
   through the bearings; install the front cap. Capture the four rotor M3 nuts
   and the central axle nut in their pockets before attaching the link.
4. Engage the magnet cup's hex socket with the rear rotor key; install the axial
   M3 retainer through the cup into the rotor nut. Do not preload the bearings or
   let the screw protrude into a mating part. Confirm free rotation and low play.
5. Glue the diametric magnet into the cup with its bottom at the modelled datum.
   Check the AS5600 status and stable angle readings through a complete rotation.
   Strong/weak/missing magnet status is a failed test, not a software workaround.
6. Once that test passes, print the rest. Build base → shoulder → upper arm →
   forearm → wrist → handle/trigger. Install each cartridge with four tab bolts,
   nuts and washers, then attach its driven link with four rotor bolts. Confirm
   real fastener/tool access and engagement at each stage before enclosing it.
7. Clamp the base. Add flexible cable loops and strain relief; move every joint
   by hand through its restricted range. Stop at interference or cable tension.
   Avoid combined folded poses that hit the base/table. Calibrate before any
   follower connection. No unrestricted 360° arm motion is intended.

## Wiring and firmware

Leader: ESP32 3V3 → mux VCC and six sensor VINs, common GND; GPIO21 → SDA,
GPIO22 → SCL on mux upstream. Mux A0/A1/A2 low (0x70), reset held high per its
board instructions. Connect one AS5600 to each channel 0–5, in joint order above.
The sensors all use address 0x36; firmware selects only one mux channel at once.
Keep I²C leads short, flexible and away from servo power; firmware uses 100 kHz.

Follower: separate ESP32 GPIO21/22 → PCA9685 SDA/SCL, VCC=3.3 V, address0x40.
GPIO25 → OE plus the external pull-up. Servo signals use channels0–5; servo
power is a separate regulated rail with common ground. Disconnect power before
rewiring. OE disables PWM, **not motor power or gravity**: support the arm and
provide a physical power-disconnect switch.

```sh
arduino-cli compile --fqbn esp32:esp32:esp32 --build-property compiler.cpp.extra_flags=-DROLE_LEADER=1 so101-mg996r/firmware/thenar
arduino-cli compile --fqbn esp32:esp32:esp32 --build-property compiler.cpp.extra_flags=-DROLE_LEADER=0 so101-mg996r/firmware/thenar
```

Both roles were compiled with ESP32 core3.3.10. Nothing was flashed or hardware
tested. Serial115200. Leader initially sends `RAW`; place it at displayed home
and send `ZERO`. Check each axis direction, using `SIGN 0 -1` etc. as required;
zeros/signs persist. `FORGET` clears calibration. Valid output is `L q0 … q5`.

Follower firmware ships **locked** (`FOLLOWER_CALIBRATED=false`). Bench-calibrate
each real servo's centre, direction, usable endpoints and pulse slope in
`calibration.h`, with horns disconnected first; only then enable the flag.
The mapping is 1:1 direct drive, not a 2:1 reduction. A claimed 180° servo is not
assumed safe over every pulse width. Re-index horns at the prescribed home.

```sh
python -m pip install numpy pyserial
python so101-mg996r/firmware/bridge.py --leader /dev/cu.LEADER
# Optional only after calibration, supported follower at home, and power safety checks:
python so101-mg996r/firmware/bridge.py --leader /dev/cu.LEADER --follower /dev/cu.FOLLOWER --arm
```

Bridge is monitor-only without a follower/`--arm`. It requires STOP acknowledgement,
fresh valid encoder data and home before requesting ARM. Firmware applies slow
slew, range/pulse checks and a 250 ms command watchdog. `STOP` disables PWM.
The bridge's table check is conservative bounding-box testing; **it is not a
self-collision/path planner**. The website is offline and never controls motors.

## Verification and limits

All twelve unique printed meshes are closed, positive-volume single shells.
Exported meshes are hash-checked before publication. Six cartridge insertions,
tab lands/shanks and rotor screw-land checks pass. Full cartridge rotation at
5° increments has zero positive overlap; 36 assembled-PCB slide samples clear.
72 full-arm poses: **70 internally clear; two folded poses collide**. Eleven
intersect the table. Both failures remain in the report, not hidden. Viewer
guards detect those samples, table contact and preserve clear home/small motions.
This is sampled CAD testing, not continuous swept-path certification. It does
not validate printed tolerances, strength, screw threads, cables, torque, sensor
noise, thermal performance or payload. Test one cartridge and unpowered assembly
before spending material on the entire robot.

## Sources / attribution

- [TheRobotStudio SO-ARM100 / SO101](https://github.com/TheRobotStudio/SO-ARM100): original geometry, Apache-2.0; preserved in `source/` with hashes.
- [Adafruit AS5600 PCB](https://github.com/adafruit/Adafruit-AS5600-Magnetic-Angle-Sensor-PCB), commit `e146e77404551f1ae0619f6627bcc4435d81b0eb`: board outline and hole centres from Eagle. Adafruit Industries, CC BY-SA; licence/attribution shipped with kit.
- [Adafruit pinouts](https://learn.adafruit.com/adafruit-as5600-magnetic-angle-sensor/pinouts): 3.3 V wiring and fixed address.
- [AS5600 datasheet](https://cdn-learn.adafruit.com/assets/assets/000/138/130/original/Magnetic_Rotary_Position_Sensor_AS5600_Datasheet.pdf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): 12-bit angle, magnetic status and magnet requirements.
- [TI TCA9548A](https://www.ti.com/product/TCA9548A): isolated selectable I²C channels.

The PCB drawing is not relicensed under the robot's licence. Keep upstream
attributions with redistributed source/derived reference geometry.

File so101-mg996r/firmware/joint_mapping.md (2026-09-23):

# R3 follower / L1 leader joint conventions

This document records the existing firmware. No firmware source or calibration was changed. Source evidence: `thenar/model.h`, `thenar/calibration.h`, `thenar/thenar.ino`, and the current published assembly manifest.

| Logical joint | Index / PCA9685 channel / TCA9548A channel | Parent → child | Command limits (deg) | Home (deg) | Neutral (µs) | Default sign |
|---|---:|---|---:|---:|---:|---:|
| shoulder_pan | 0 | base_link → shoulder_link | −85 … +85 | 0 | 1500 | +1 |
| shoulder_lift | 1 | shoulder_link → upper_arm_link | −80 … +80 | −25 | 1500 | +1 |
| elbow_flex | 2 | upper_arm_link → lower_arm_link | −80 … +80 | +35 | 1500 | +1 |
| wrist_flex | 3 | lower_arm_link → wrist_link | −80 … +80 | 0 | 1500 | +1 |
| wrist_roll | 4 | wrist_link → gripper_link | −85 … +85 | 0 | 1500 | +1 |
| gripper | 5 | gripper_link → moving_jaw_so101_v1_link | 0 … +70 | +20 | 1500 | +1 |

Positive geometric angle is right-hand rotation about each joint datum's local +Z. These axes have different orientations in the global frame; +Z is not a global-axis instruction. Joint 5 rotates the moving jaw directly against the fixed gripper-body finger.

The follower uses `current[i]` / `goal[i]`, with `pulse = SERVO_ZERO_US[i] + q[i] * US_PER_DEGREE[i] * SERVO_SIGN[i]`. The stored default slope is 5.555556 µs/degree and default sign is +1 for all channels. Pulse guards are 1000–2000 µs for every channel. These are SOURCE VERIFIED software values; actual neutral indexing, positive physical servo rotation, pulse endpoints and mechanically safe travel are UNVERIFIED. The CAD convention cannot establish them. `FOLLOWER_CALIBRATED=false` remains unchanged.

Each axis is direct drive (1:1). The historical custom arm's 2:1 calibration does not apply. Servo control is on PCA9685 outputs 0–5, not six direct ESP32 servo GPIOs. Both controllers use ESP32 GPIO21 SDA / GPIO22 SCL. The follower driver is at I²C address 0x40; GPIO25 controls OE. The leader mux is at 0x70 and selects one of six AS5600 sensors at address 0x36.

The leader's `ZERO` command stores raw sensor readings at HOME, not at geometric q=0. Its conversion is `q[i] = model::home[i] + signs[i] * wrappedDegrees(raw[i], zeros[i])`. `wrappedDegrees` uses a 12-bit signed wrap and 360/4096 degrees/count. Sensor signs default to +1 and can be calibrated through `SIGN i +/-1`; neither sensor signs nor stored hardware zero readings are supplied in the project.

The source's preview/command limits do not prove independent or combined collision-free travel. The follower's sampled table intersections and the leader's folded collisions remain documented limitations. Physical min/max values are UNVERIFIED and must not be inferred from the 180-degree servo label.

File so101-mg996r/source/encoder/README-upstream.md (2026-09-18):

## Adafruit AS5600 Magnetic Angle Sensor - STEMMA QT PCB

<a href="http://www.adafruit.com/products/6357"><br/>
Click here to purchase one from the Adafruit shop</a>

PCB files for the Adafruit AS5600 Magnetic Angle Sensor - STEMMA QT. 

Format is EagleCAD schematic and board layout
* https://www.adafruit.com/product/6357

### Description

Add rotational sensing - without a mechanical connection - with the Adafruit AS5600 Magnetic Angle Sensor. Featuring the classic ams AS5600, this board can sense a rotating N/S magnetic field up to 3mm away from the chip body. These sensors are often used to create 'frictionless' rotary encoders or potentiometers, without the risk of mechanical failure or noise. Magnetic angle sensors get the best of 'both worlds': like rotary encoders they can rotate freely 360 degrees around, and like potentiometers, they have absolute location detection.

All you need is a microcontroller or microcomputer with I2C - we have Arduino, Python and CircuitPython driver support. Then, identify the north and south of a magnet: we recommend a rare earth magnet. Note that many round magnets have the N/S on alternate 'coin face' sides, so you'll need to rotate it on the edge. Place the magnet near the middle of the chip and rotate it in place. The firmware will detect the magnetic field and report the angle from 0 to 359 with 0.1° precision and 0.4° accuracy.

To make usage plug-and-play, we added SparkFun qwiic-compatible STEMMA QT connectors for the I2C bus, so you don't even need to solder the I2C and power lines. Simply wire up to your favorite micro using a STEMMA QT adapter cable. The Stemma QT connectors also mean the AS5600 can be used with our various associated accessories. QT Cable is not included, but we have a variety in the shop.

Comes as a fully assembled breakout board a small bit of header. Some light soldering is required to attach the header for use in a breadboard. 

### License

Adafruit invests time and resources providing this open source design, please support Adafruit and open-source hardware by purchasing products from [Adafruit](https://www.adafruit.com)!

Designed by Limor Fried/Ladyada for Adafruit Industries.

Creative Commons Attribution/Share-Alike, all text above must be included in any redistribution. 
See license.txt for additional details.

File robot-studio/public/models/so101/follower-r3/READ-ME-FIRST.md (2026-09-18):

# SO-101 → MG996R follower R3

This is a **nominal-fit CAD assembly prototype**, derived from the exact
original SO-101 meshes. It is not a physically tested or payload-rated robot.
Use the seven files in `print-parts/`, or the P1S layouts in `plates/`.
Do not substitute stock SO-101 plates or mix the earlier R1/R2 parts into R3.

**Full-plate printing is not cleared yet.** Both plates generated G-code, but
plate 1 logged two slicer clipping errors. An independent coarse toolpath screen
also flagged 43 candidate missing cross-sections on plate 1 and 12 on plate 2.
Those candidates are not confirmed defects: the screen does not fully account
for holes, thin features or bridge-layer placement. They still require review.
The ZIP therefore contains the seven converted STLs and two **geometry-only**
3MF layouts, **not approved sliced projects or ready-to-run G-code**.
Do not start a full arm print just because the meshes are closed.

The passive encoder leader is a separate L1 kit: see `ENCODER-LEADER.md` in
the repository. Both ESP32 firmware roles are provided, but the follower ships
locked until physical calibration. Electronics housings are not included;
the website does not control hardware.

## What changed

- Six MG996R body cavities, mounting ledges and four slotted tab holes per motor.
- Six Ø20 mm metal-disc horn interfaces with four M3 holes on a Ø14 mm pitch circle.
- Joint-travel reliefs, rather than a zero-angle cavity alone.
- An 8 mm local extension between the wrist motors; joint placement moves with it.
- Base, shoulder and forearm fixed bracket pairs joined into single printing units.
  Their connection no longer depends on threaded holes in an STS3215 servo case.
- Straight underside access to the mounting nuts, and horn-screw head recesses.
- The obsolete WaveShare STS controller plate is excluded from the MG996R print kit.

The main links retain the source design. No whole-arm mesh scaling or unrelated
replacement robot is used. The forearm and shoulder brackets have documented
sub-0.1 mm local overlaps to turn tangential source seams into solid printed joints.
The source STLs and STEP files are preserved in the project, unchanged.

## Nominal hardware dimensions used

| Feature | CAD value |
|---|---|
| MG996R case, excluding shaft and tabs | 40.9 × 20 × 37 mm |
| Case bottom to shaft tip | 42.7 mm, TowerPro configure-table datum |
| Tab span / thickness | 54 / 2.6 mm |
| Case bottom to tab underside | 26.8 mm |
| Fixed case clearance | 0.3 mm per side |
| Tab-hole centre spacing | 49.5 × 10 mm, nominal assumption |
| Printed tab slots | 5 × 3.4 mm |
| Mount ledge | 4 mm |
| Metal horn option | 25T; Ø20 mm disc; 4 M3 holes on Ø14 mm PCD |
| Horn stack / printed mating plate | 4.5 / 6 mm |
| Purchased servo travel | User-confirmed 180°, positional |

The dimensions are nominal MG996R design inputs, as requested, not measurements
of the Amazon units. The Ø20 mm metal discs are a specified hardware option;
the plastic horns supplied in a servo box are not automatically interchangeable.
Use a horn that matches the actual spline. No plastic spline is printed.

Sources: [TowerPro MG996R](https://towerpro.com.tw/product/mg996r/) and
[the specified metal-disc drawing](https://www.handsontec.com/dataspecs/accessory/25T%20Servo%20Disc.pdf).

## Seven printed units

| Printing unit | Original source pieces incorporated |
|---|---|
| Base | Base_SO101 + Base_motor_holder_SO101 |
| Shoulder | Rotation_Pitch_SO101 + Motor_holder_SO101_Base |
| Upper arm | Upper_arm_SO101 |
| Forearm | Under_arm_SO101 + Motor_holder_SO101_Wrist |
| Wrist pitch/roll | Wrist_Roll_Pitch_SO101, locally extended 8 mm |
| Gripper body | Wrist_Roll_Follower_SO101 |
| Moving jaw | Moving_Jaw_SO101 |

Intermediate per-source files in the project are engineering intermediates, not
an alternate kit: use the seven joined printing units above.

## Prototype BOM

| Item | Quantity | Specification |
|---|---:|---|
| Positional MG996R | 6 | Four reported owned; two more for a complete follower |
| Matching metal disc horns | 6 | Ø20 mm, 25T option, four M3 tapped holes on Ø14 mm PCD |
| Horn centre-retaining screws | 6 | Correct screws for the servo shafts; use supplied matching screws, not an assumed M3 thread |
| Servo mounting screws | 24 | M3 × 12 mm, four per servo; nominal 2.6 mm tab and 4 mm ledge |
| M3 nuts | 24 | Standard 5.5 mm across flats; 6.8 mm access bores |
| M3 flat washers | 48 | About Ø7 mm, one under each mounting screw head and nut |
| Horn-to-printed-link screws | 24 | M3 × 8 mm, no extra washer in the modeled 6 mm plate + 2 mm thread-engagement stack |
| Printed units | 7 | The R3 kit, PETG |
| Desk clamps | 2 | Appropriate for the existing base and desk; clamp the base before a loaded test |
| ESP32 development board | 1 | Proposed controller; USB cable ×1 |
| PCA9685 PWM breakout | 1 | Six channels; 3.3 V logic with ESP32 |
| Regulated servo supply | 1 | 6 V, 10–15 A planning range; verify the actual units and wiring |
| Fused servo distribution and DC-rated cutoff | 1 set | Separate servo power path; common controller ground |
| Servo extension leads and signal wiring | 1 set | Route and choose lengths after the unpowered assembly |

No external follower encoders are required. The stock WaveShare STS serial-bus
controller is not the PWM driver for MG996Rs. A controller mounting enclosure,
cable clips and leader encoder BOM are not part of the printable R3 release.
Do not use the earlier custom robot's 2:1 firmware calibration on these direct-drive joints.

## P1S setup

Two geometry-only 3MF layouts contain the seven R3 units, with 12 mm between
part bounding boxes, a 35 mm front reserve and a 5 mm outer reserve.
They are candidates selected from 16 packing combinations, not a proof of the
globally fastest or minimum-plate solution.

Profile: Bambu P1S / 0.4 mm nozzle / textured PEI / generic PETG / 0.20 mm layers /
4 walls / 25% gyroid / automatic normal supports / 5 mm brim / print by layer.
The `plate-report.json` gives actual slicer outcomes and time/material estimates.
The current Arachne estimates are 10 h 46 min / 277.89 g for plate 1 and
9 h 8 min / 218.99 g for plate 2: approximately **19 h 54 min and 497 g PETG**
combined, including support/brim. These are provisional, not validated print
times or a guarantee of correct toolpaths. Inspect every layer in Bambu Studio,
especially screw ledges and horn plates, before a single-part fit print.
Sliced-file downloads remain withheld while the diagnostic review is unresolved.
Remove support from slots, body pockets, nut-access bores and horn holes before fitting.

## Assembly/test sequence

1. After reviewing its sliced layers, print and fit one mount first: the wrist
   pitch/roll or gripper unit can be selected individually in Bambu Studio. The earlier small
   body/tab gauge remains available separately, but is not a replacement arm part.
2. With power disconnected and the horn removed, insert each motor through the
   +shaft-side opening of its corresponding unit. Seat the tabs on the ledges.
3. Fit the four M3 mounting screws, washers and nuts. Nuts are accessed from
   beneath the ledges. Tighten evenly; do not crush the printed tabs or servo case.
4. Establish the servo's neutral position unloaded before final horn indexing.
   Disconnect power again before attaching a link. Never force a powered shaft.
5. Screw each metal disc to its driven printed plate using four M3 × 8 screws.
   The central opening provides access to the servo's own horn-retaining screw.
   Check real screw-tip clearance and thread engagement before tightening.
6. Work outward: base → shoulder → upper arm → forearm → wrist → gripper → jaw.
   Support the moving links during assembly. Check the complete unpowered travel,
   cable exits and access with the real fasteners before attempting a powered test.

## What the verification does—and does not—establish

The files are re-imported after export. Checks cover closed single-shell meshes,
nominal hornless insertion at 27 heights per joint, tab/horn screw passages and
material beneath the screw heads, plus 72 sampled robot poses. The JSON reports
record file hashes so changed geometry cannot inherit an old pass.

The collision report checks printed units and nominal servo/horn envelopes.
It does not model every fastener, wire, connector, screwdriver or manufacturing
tolerance. It is sampled, not a continuous-motion proof. Some combinations of
otherwise valid joint angles go through the tabletop; the website's slider guard
does not constitute a hardware safety controller.

**This prototype relies on the MG996R's single-sided output support.** Stock
STS rear-idler geometry is relieved where the larger case needs space; no invented
rear shaft is shown. Shaft/bearing loads, PETG stiffness, torque and temperature
need bench testing. No payload or continuous-duty rating is assigned. Full-reach
gravity loads may require counterbalancing; published stall torque is not a usable
continuous torque specification. Keep the arm supported for initial tests.

Neither a closed STL, a collision-free sampled pose nor successful slicing proves
that the assembled powered robot works. The leader encoder conversion remains separate work.

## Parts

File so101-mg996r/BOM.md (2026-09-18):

# MG996R follower and encoder leader — staged BOM

## Current R3 follower BOM

Use the **[R3-PRINT.md prototype BOM](R3-PRINT.md#prototype-bom)** for the seven
converted arm units. It specifies six MG996Rs (four owned, two additional), six
metal disc horns, 24 M3 × 12 tab screws, 24 nuts, 48 washers, 24 M3 × 8 horn
screws, six matching horn-retaining screws, controller/power planning and clamps.
Two geometry-only P1S layouts are included; sliced downloads are withheld pending
toolpath review. This remains an unpowered, nominal-fit assembly prototype.

The R1 list below is preserved as **historical background**, not the R3 assembly
or fastener schedule. The encoder leader and electronics enclosure remain open.

## Historical R1 bench-fit BOM

Revision: 2026-09-17, bench-fit prototype R1. **Not a final full-arm procurement
release.** Your purchased MG996Rs have user-confirmed 180° travel; their dimensions,
horns and usable powered endpoints are not measured yet.

## Print/test now: one unpowered servo

| Item | Quantity | Specification / purpose |
|---|---:|---|
| Your purchased MG996R | 1 from the existing 4 | Leave disconnected; remove its horn for insertion |
| Body/tab gauge | 1 print | 41.5 × 20.6 mm opening; nominal 49.5 × 10 mm hole centres |
| Original-derived wrist holder | 1 print, after gauge fit | 4 mm tab ledges, 5 × 3.4 mm slots; bench only |
| Horn-pattern gauge | 1 optional print | Checks proposed 14 mm PCD, four-hole disc; not spline fit |
| M3 × 12 mm machine screws | 4 | Only if actual tab holes accept M3 without drilling |
| M3 hex nuts | 4 | Nominal 5.5 mm across flats; access bores are 6.8 mm |
| M3 flat washers | 8 | One under each head and nut; approximately 7 mm outside diameter |
| PETG | About 5 g gauges / 24 g full test plate | Slicer estimates including supports/brim; extra for purge |
| Calipers, ruler, small driver and nut tool | 1 set | Record actual dimensions; do not force mismatched hardware |

The M3 × 12 stack assumes a 4 mm ledge, 2.6 mm tab, about 1 mm combined washer
thickness and a 2.4 mm nut. Confirm actual stack before tightening; screw tips must
not touch the servo. No full-arm screws, bearing axles or spline interfaces are
implicitly approved by this test.

## Planned follower: six controlled axes

| Component | Total needed | Already owned / purchase status |
|---|---:|---|
| Matching positional MG996R servos | 6 | 4 reported owned; 2 more after fit/travel checks |
| Metal servo horns with matching spline | 6 | Supplied horns unmeasured. Proposed option: 25T, Ø20 mm disc, four M3 holes on Ø14 mm PCD; verify on your shaft first |
| Correct central horn-retaining screws | 6 | Use screws supplied for the exact shaft; do not assume M3 |
| ESP32 development board | 1 | Proposed controller; matching USB cable ×1 |
| PCA9685 PWM breakout | 1 | Six channels used; 3.3 V logic; replaces stock STS bus-controller function |
| Regulated external servo power supply | 1 | 6 V, 10–15 A planning range; final sizing from measured units, load and wiring |
| Servo power distribution / protected harness | 1 | Rated for chosen current, individual power branches, common ground; no unverified breakout terminal or breadboard for total current |
| DC-rated power cutoff, fuse holder and fuse | 1 each | Ratings selected with final supply, conductors and connectors; cutoff interrupts servo power |
| Servo extension leads | Up to 6 | Lengths after actual routing, slack at travel limits |
| I²C / signal wiring and connectors | 1 set | ESP32 to PCA9685, secure connections and strain relief |
| Servo-tab screws / nuts / washers | Up to 24 / 24 / 48 | Intended four-per-servo pattern; NOT a released full-arm fastener schedule |
| Horn-to-link screws | TBD | Length from final engagement; tips must not touch servo case |
| Opposite-side bearings, shafts, spacers, retainers | TBD | Essential load-path redesign; do not order guessed sizes |
| Link/base fasteners, inserts and desk clamps | TBD | Counts/lengths follow final interfaces; stock STS kit is not automatically transferable |
| Printed arm parts | Pending | Original 11 follower parts are sources, not MG996R-ready prints |

No external encoders are required on the follower under your requested approach.
MG996Rs have internal position control, but the ordinary 3-wire interface does not
return measured joint position. An animation cannot prove a physical joint followed
its command.

The stock WaveShare STS serial-bus controller is not the PWM driver for this
conversion. Its stock mounting plate does not establish ESP32/PCA9685 fit.
Electronics mounting and the final harness remain to be designed.

### Power and operating limits

TowerPro publishes 4.8–6.6 V and 1.4 A stall current for its own MG996R. Six such
units total 8.4 A at that stated stall current, before headroom; your generic units
may differ. The supply range above is a planning estimate, not a tested rating.
Never deliberately stall all joints to size the supply. Do not power servos from
USB, the ESP32 3.3 V pin, or its regulator.

PCA9685 VCC uses controller logic voltage; servo power is separate, with common
ground. Software output-disable does not replace a physical power cutoff.
Support the arm before cutting power because joints can drop. No payload, speed,
continuous torque or thermal rating is established. Test one unloaded servo first,
then a mechanically approved and supported joint.

Sources: [TowerPro specification](https://towerpro.com.tw/product/mg996r/),
[Adafruit driver power/pinouts](https://learn.adafruit.com/16-channel-pwm-servo-driver/pinouts),
[proposed metal horn](https://www.handsontec.com/dataspecs/accessory/25T%20Servo%20Disc.pdf).
These reference specifications do not prove the Amazon unit's dimensions.

## Later: passive encoder leader, not mechanically converted yet

| Component | Planned quantity | Status |
|---|---:|---|
| AS5600 angle-sensor breakout | 6 | Five arm axes plus trigger; select exact board outline/hole pitch |
| Diametrically magnetized on-axis magnets | 6 | Match sensor field/gap requirements; not axially magnetized discs |
| TCA9548A I²C multiplexer breakout | 1 | Separates identical-address sensor channels |
| Leader ESP32 and USB cable | 1 each, optional | For a separate controller; short shared-controller bench setup can use follower ESP32 |
| Passive bearings/bushings, axles and spacers | TBD | Servo bodies cannot be removed without replacing their support function |
| Trigger spring, magnet and sensor carriers | TBD | Geometry and spring force not released |
| Leader wiring and strain relief | 1 set | Lengths after routing |

The planned leader uses **no MG996R motors**. Encoder cartridges and bearings are
not present in the displayed stock leader. Evaluate one sensor/magnet pair first,
not six mechanically unverified modules.

Sources: [AS5600 datasheet](https://look.ams-osram.com/m/7059eac7531a86fd/original/AS5600-DS000365.pdf),
[magnetic setup](https://look.ams-osram.com/m/4f8342513a447495/original/AS5600_UG000254_2-00.pdf),
[TI TCA9548A](https://www.ti.com/product/TCA9548A).

## What blocks the complete robot

The full-arm study still fails its 44 sampled poses: moving-link interferences,
wrist-servo-to-wrist-servo overlap, incomplete horn/opposite-side support interfaces,
and two open draft meshes. The standalone holder test has not been inserted into
that assembly or represented as solving the other failures. A complete verified
BOM depends on fixing those interfaces.

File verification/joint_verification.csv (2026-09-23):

Joint | Parent | Child | Axis | Minimum | Maximum | Zero | Movement PASS/FAIL | Axis PASS/FAIL | Collision result | Mate result | Evidence | Notes
J1 | Base_MG996R_R3 | Shoulder_MG996R_R3 | local +Z | -85 | 85 | 0 | PASS | PASS | 15 discrete CAD-mesh poses checked; only source-intended shaft/horn engagement above 0.5 mm3 | PASS | solidworks\evidence\joint_motion_measurements.json | Native mate-driven motion checked; mouse dragging and swept collision certification remain unverified.
J2 | Shoulder_MG996R_R3 | Upper_arm_MG996R_R3 | local +Z | -80 | 80 | 0 | PASS | PASS | Table penetration at isolated maximum; 15 discrete CAD-mesh poses checked; only source-intended shaft/horn engagement above 0.5 mm3 | PASS | solidworks\evidence\joint_motion_measurements.json | Native mate-driven motion checked; mouse dragging and swept collision certification remain unverified.
J3 | Upper_arm_MG996R_R3 | Forearm_MG996R_R3 | local +Z | -80 | 80 | 0 | PASS | PASS | Table penetration at isolated maximum; 15 discrete CAD-mesh poses checked; only source-intended shaft/horn engagement above 0.5 mm3 | PASS | solidworks\evidence\joint_motion_measurements.json | Native mate-driven motion checked; mouse dragging and swept collision certification remain unverified.
J4 | Forearm_MG996R_R3 | Wrist_pitch_roll_MG996R_R3 | local +Z | -80 | 80 | 0 | PASS | PASS | 15 discrete CAD-mesh poses checked; only source-intended shaft/horn engagement above 0.5 mm3 | PASS | solidworks\evidence\joint_motion_measurements.json | Native mate-driven motion checked; mouse dragging and swept collision certification remain unverified.
J5 | Wrist_pitch_roll_MG996R_R3 | Gripper_body_MG996R_R3 | local +Z | -85 | 85 | 0 | PASS | PASS | 15 discrete CAD-mesh poses checked; only source-intended shaft/horn engagement above 0.5 mm3 | PASS | solidworks\evidence\joint_motion_measurements.json | Native mate-driven motion checked; mouse dragging and swept collision certification remain unverified.
J6 | Gripper_body_MG996R_R3 | Moving_jaw_MG996R_R3 | local +Z | 0 | 70 | 0 | PASS | PASS | 15 discrete CAD-mesh poses checked; only source-intended shaft/horn engagement above 0.5 mm3 | PASS | solidworks\evidence\joint_motion_measurements.json | Native mate-driven motion checked; mouse dragging and swept collision certification remain unverified.

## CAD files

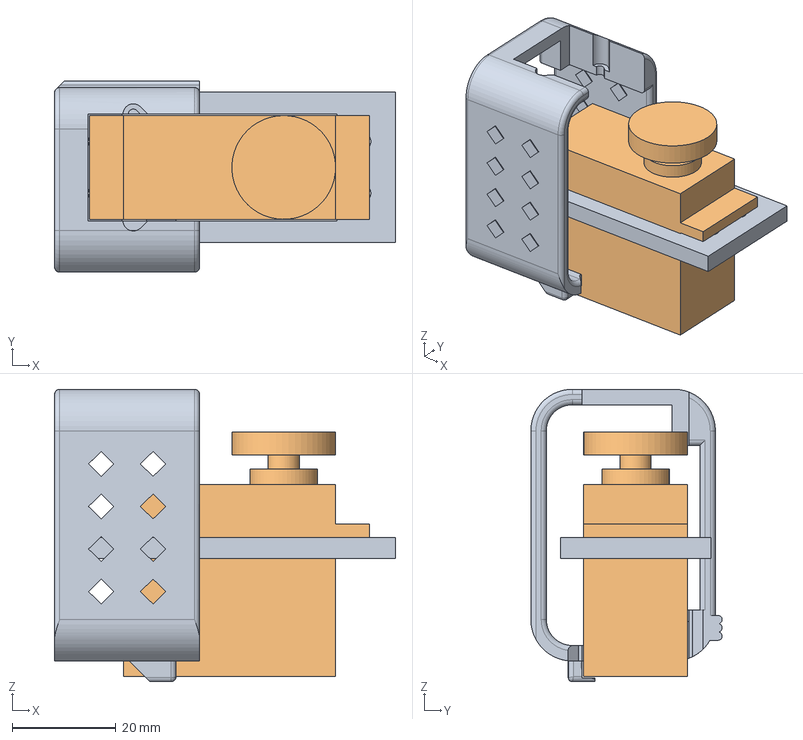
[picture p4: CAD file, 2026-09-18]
so101-mg996r/output/fit-test-r1/BENCH_FIT_ASSEMBLY.step
65.8 x 36.9 x 56.4 mm
bench_holder
nominal_servo

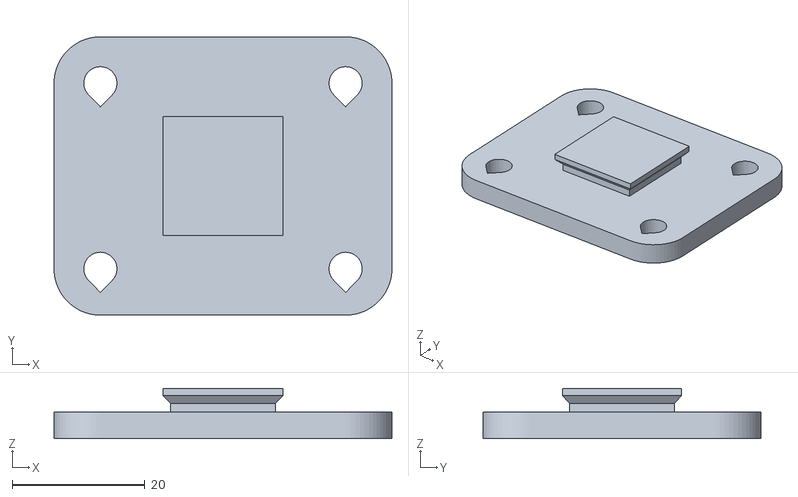
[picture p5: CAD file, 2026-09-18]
robot-studio/public/models/so101/clearance/WaveShare_Mounting_Plate_SO101_MG996R_clearance_DRAFT.stl
51.0 x 42.0 x 7.60

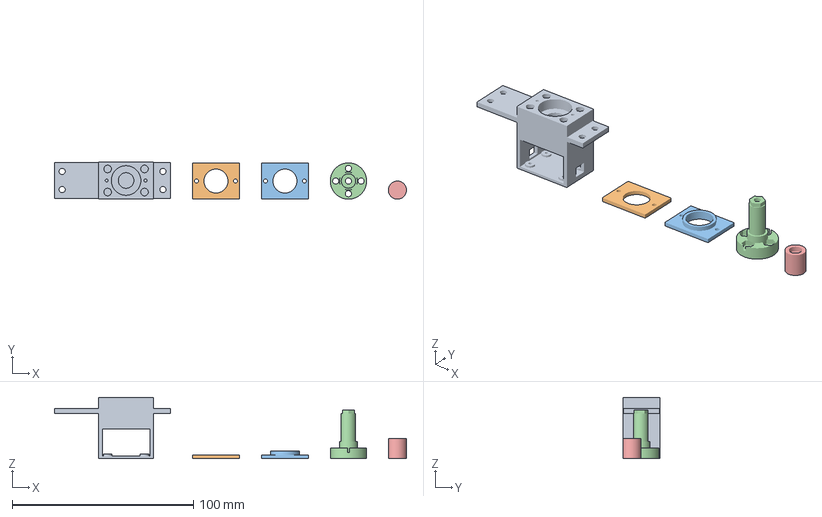
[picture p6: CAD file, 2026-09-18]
robot-studio/public/models/so101/encoder-leader-l1/P1S_ENCODER_CARTRIDGE_FIT.3mf
194.0 x 20.6 x 33.8 mm
Encoder_cartridge_L1
Bearing_cap_front_L1
Bearing_cap_rear_L1
Encoder_rotor_L1
Magnet_cup_L1

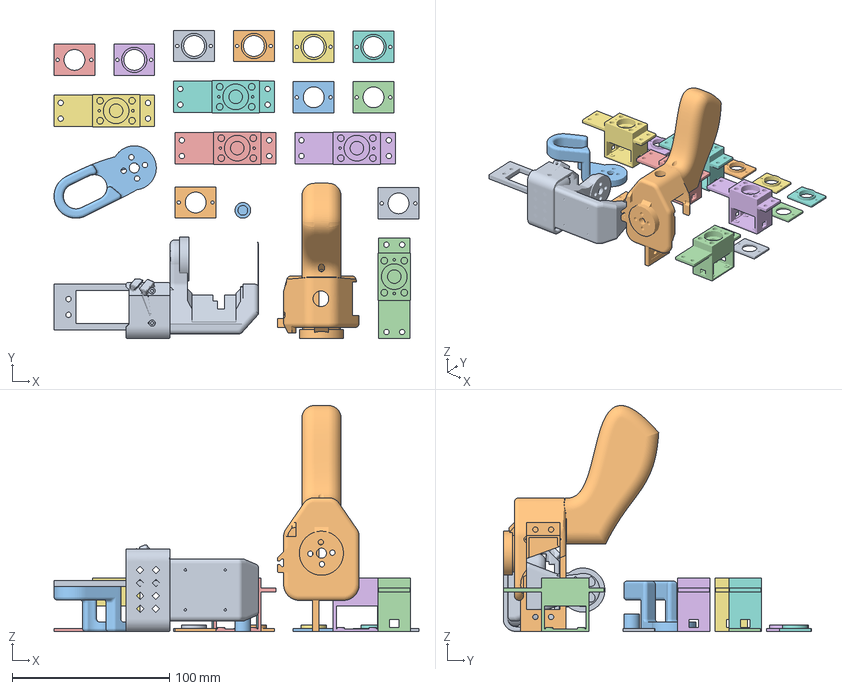
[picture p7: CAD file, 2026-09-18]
robot-studio/public/models/so101/encoder-leader-l1/plates/P1S_ENCODER_L1_02.3mf
231.9 x 196.0 x 143.6 mm
Shoulder_Encoder_L1_1
Handle_Encoder_L1_1
Trigger_Encoder_L1_1
Encoder_cartridge_L1_2
Encoder_cartridge_L1_3
Encoder_cartridge_L1_4
Encoder_cartridge_L1_5
Encoder_cartridge_L1_6
Bearing_cap_front_L1_2
Bearing_cap_front_L1_3
Bearing_cap_front_L1_4
Bearing_cap_front_L1_5
Bearing_cap_front_L1_6
Bearing_cap_rear_L1_1
Bearing_cap_rear_L1_2
Bearing_cap_rear_L1_3
Bearing_cap_rear_L1_4
Bearing_cap_rear_L1_5
Magnet_cup_L1_6

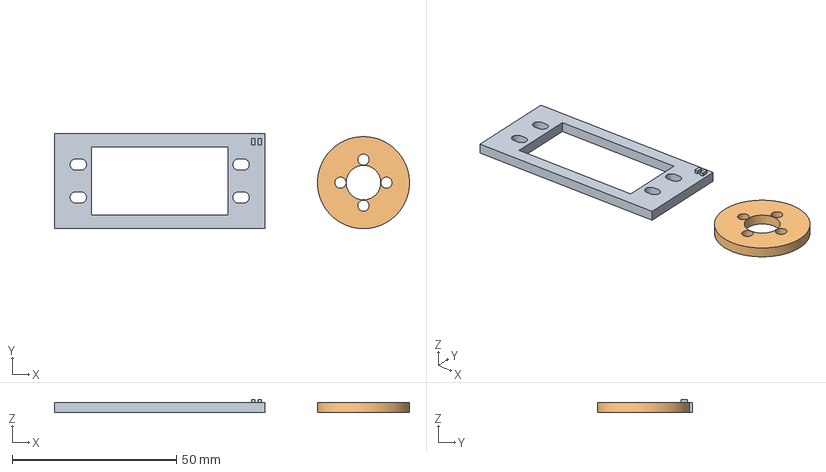
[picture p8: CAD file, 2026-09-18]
robot-studio/public/models/so101/fit-test/P1S_QUICK_GAUGES_ONLY_sliced.3mf
108.0 x 29.0 x 4.00 mm
MG996R_body_tab_gauge
Horn_14mm_PCD_gauge

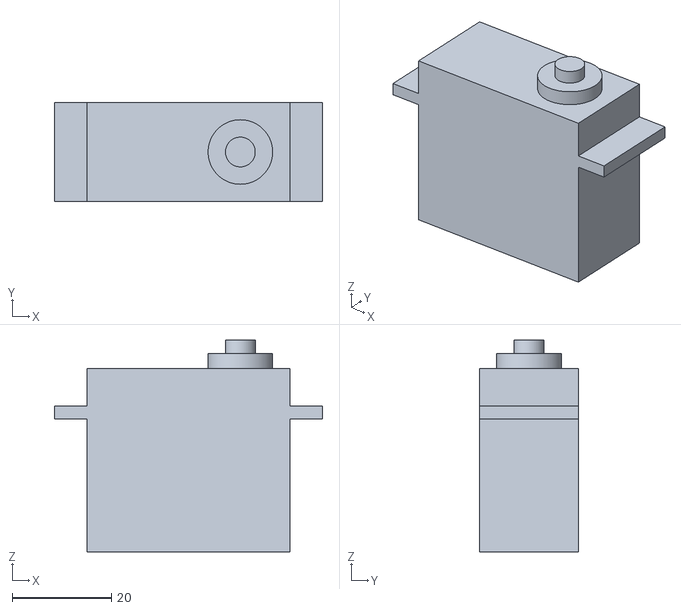
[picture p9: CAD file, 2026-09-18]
robot-studio/public/models/so101/follower-r3/MG996R_body_reference.stl
54.0 x 20.0 x 42.7

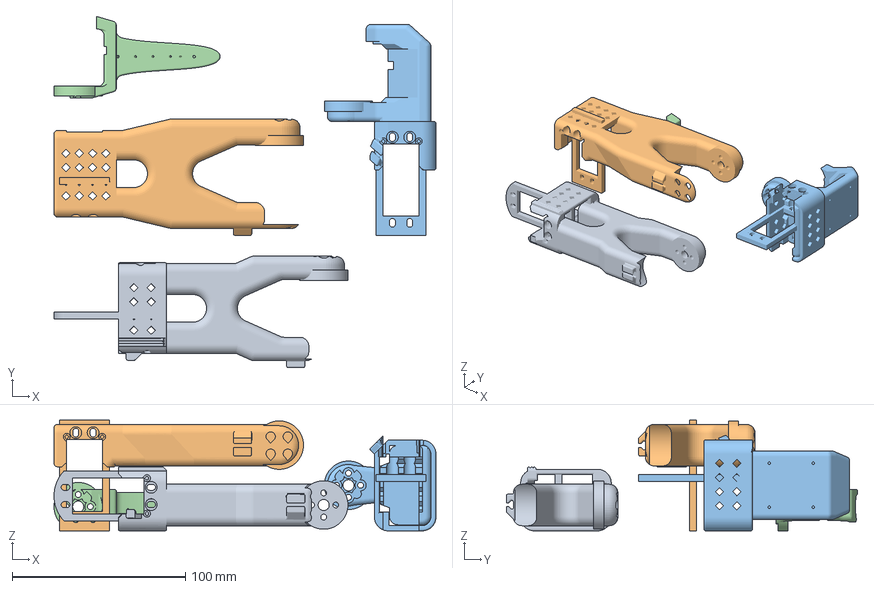
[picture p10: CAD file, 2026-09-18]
robot-studio/public/models/so101/follower-r3/plates/P1S_MG996R_R3_01.3mf
220.7 x 202.9 x 64.0 mm
Forearm_MG996R_R3
Upper_arm_MG996R_R3
Shoulder_MG996R_R3
Moving_jaw_MG996R_R3

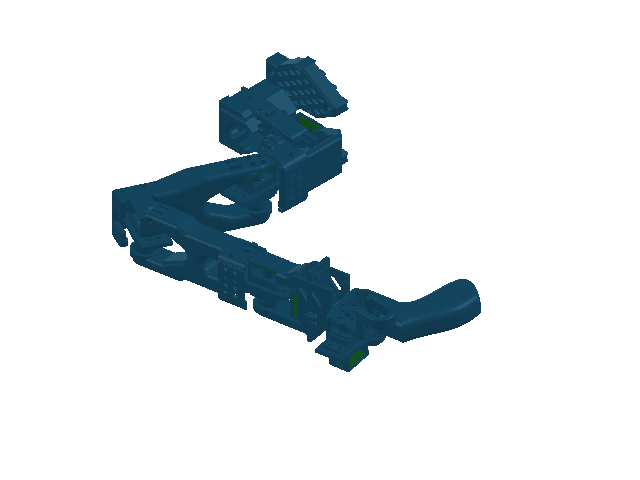
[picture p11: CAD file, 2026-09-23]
solidworks/assemblies/SO101_Leader_Master.SLDASM
Base_Encoder_L1
Shoulder_Encoder_L1
Upper_arm_Encoder_L1
Forearm_Encoder_L1
Wrist_pitch_roll_Encoder_L1
Handle_Encoder_L1
Trigger_Encoder_L1
Encoder_cartridge_L1 x 6
Bearing_cap_front_L1 x 6
Bearing_cap_rear_L1 x 6
Encoder_rotor_L1 x 6
Magnet_cup_L1 x 6
AS5600_PCB_L1 x 6
AS5600_chip_L1 x 6
AS5600_connectors_L1 x 6
688_bearing_front_L1 x 6
688_bearing_rear_L1 x 6
Diametric_magnet_L1 x 6

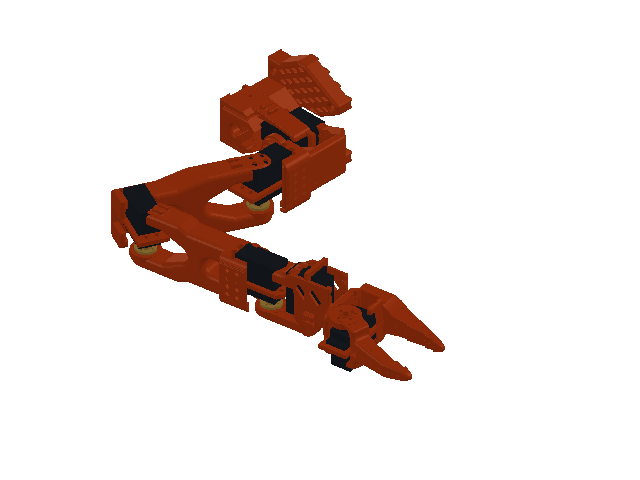
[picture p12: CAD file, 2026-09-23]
solidworks/assemblies/SO101_Follower_Master.SLDASM
Base_MG996R_R3
MG996R_Nominal_R3 x 6
Shoulder_MG996R_R3
Upper_arm_MG996R_R3
Forearm_MG996R_R3
Wrist_pitch_roll_MG996R_R3
Gripper_body_MG996R_R3
Moving_jaw_MG996R_R3
Metal_Horn_D20_PCD14_R3 x 6

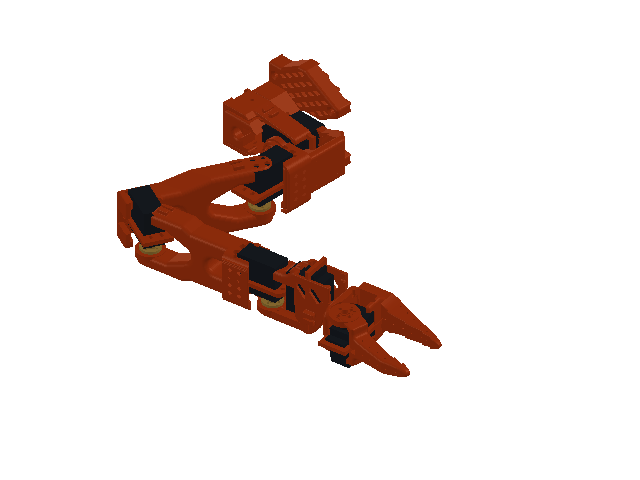
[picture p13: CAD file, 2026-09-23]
solidworks/assemblies/SO101_Follower_Reconstruction_WIP.SLDASM
Base_MG996R_R3
MG996R_Nominal_R3 x 6
Shoulder_MG996R_R3
Upper_arm_MG996R_R3
Forearm_MG996R_R3
Wrist_pitch_roll_MG996R_R3
Gripper_body_MG996R_R3
Moving_jaw_MG996R_R3
Metal_Horn_D20_PCD14_R3 x 6

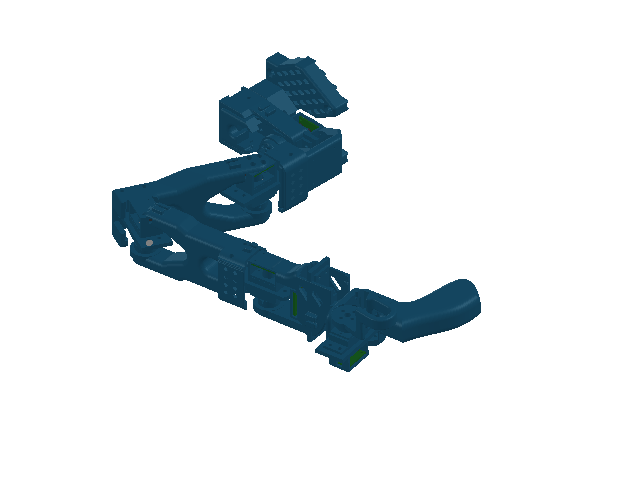
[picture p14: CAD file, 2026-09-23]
solidworks/checkpoints/Leader_before_limit_correction.SLDASM
Base_Encoder_L1
Shoulder_Encoder_L1
Upper_arm_Encoder_L1
Forearm_Encoder_L1
Wrist_pitch_roll_Encoder_L1
Handle_Encoder_L1
Trigger_Encoder_L1
Encoder_cartridge_L1 x 6
Bearing_cap_front_L1 x 6
Bearing_cap_rear_L1 x 6
Encoder_rotor_L1 x 6
Magnet_cup_L1 x 6
AS5600_PCB_L1 x 6
AS5600_chip_L1 x 6
AS5600_connectors_L1 x 6
688_bearing_front_L1 x 6
688_bearing_rear_L1 x 6
Diametric_magnet_L1 x 6

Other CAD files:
solidworks/checkpoints/Follower_visual_regression.SLDASM
solidworks/checkpoints/follower_before_final_range_validation.SLDASM
solidworks/checkpoints/leader_before_native_limit_replacement.SLDASM
robot-studio/public/models/so101/Base_SO101.stl
robot-studio/public/models/so101/Base_motor_holder_SO101.stl
robot-studio/public/models/so101/Ender_Follower_SO101_P1S.3mf
robot-studio/public/models/so101/Ender_Leader_SO101_P1S.3mf
robot-studio/public/models/so101/Handle_SO101.stl
robot-studio/public/models/so101/Motor_holder_SO101_Base.stl
robot-studio/public/models/so101/Motor_holder_SO101_Wrist.stl
robot-studio/public/models/so101/Moving_Jaw_SO101.stl
robot-studio/public/models/so101/Rotation_Pitch_SO101.stl
robot-studio/public/models/so101/Trigger_SO101.stl
robot-studio/public/models/so101/Under_arm_SO101.stl
robot-studio/public/models/so101/Upper_arm_SO101.stl
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

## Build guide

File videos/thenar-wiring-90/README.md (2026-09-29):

# Thenar one-ESP32 connection film

Editable HyperFrames source for the 90-second video published at
`https://nickthelegend.github.io/thenar-arms/wiring-video.html`.

The film illustrates the **one ESP32 for the encoder leader + Pi 4B directly to
PCA9685 for the follower** arrangement. It is a connector-level instructional
diagram, not real footage or evidence of a working electrical build. Read
`so101-mg996r/RASPBERRY-PI-DIRECT-FOLLOWER.md` before wiring anything; the
existing `firmware/bridge.py` still targets a second ESP32.

From this directory:

```sh
npm run check
npm run render -- --quality delivery --output renders/thenar-wiring-one-esp-90s.mp4
```

The checked 1920 × 1080, 30 fps H.264 render is 90 seconds. The site serves
it at `robot-studio/public/video/thenar-wiring-90s.mp4` to preserve the earlier
video URL while replacing the obsolete two-ESP32 content.

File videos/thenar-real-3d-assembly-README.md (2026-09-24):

# Thenar real 3D assembly film

[Watch the 180-second MP4](../robot-studio/public/video/thenar-real-3d-assembly-180s.mp4) · 1920 × 1080 · 25 fps

This replaces the earlier static-card assembly guide. It loads the 27 actual project STL meshes through the same Three.js assembly manifest as the robot viewer and animates 92 mesh instances through 80 physical assembly steps into their recorded CAD transforms. It shows the passive leader L1 first, joint by joint, then the MG996R follower R3, servo by servo, and finishes with both complete assemblies.

The video renders printed links, six encoder cartridges, six AS5600 board assemblies, twelve 688ZZ bearings, six rotors, six magnet cups/magnets, six MG996R body reference meshes, and six metal horn reference meshes. Hardware without an STL in the manifest—individual screws, nuts, washers, cables, power supply, and boards outside the arm—is called out in labels but **not falsely modeled or placed**. [Raspberry Pi 4B wiring](../so101-mg996r/RASPBERRY-PI-4B.md) is documented separately.

The 3D placements are nominal CAD targets, **not proof of physical fit, strength, collision-free travel or successful electronics operation**. Dry-fit your actual purchased servos/horns and first cartridge, verify bearing/magnet readings, and test all joint motions unpowered before applying servo power.

To watch the real-time 3D animation in the project website, start `robot-studio` with `npm run dev` and open `/assembly-video.html`. The MP4 was captured directly from that Three.js scene, not made from static slides.

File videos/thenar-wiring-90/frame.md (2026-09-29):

---
background: "#f1eee5"
foreground: "#162c32"
accent: "#0b7880"
secondary: "#4e7080"
warning: "#b5452a"
font_display: "Arial Black"
font_data: "Arial"
---

Concept: a printed field-service wiring chart presents one large connection map at a time. The previous all-at-once bench made its pin labels unreadable at normal browser size; the revised view uses full-frame tables with large physical pin numbers and explicit power separation.

Focal: one numbered step and a large source-to-destination mapping. Supporting detail: six encoder channels, exact Pi physical pin numbers, connector labels, and separate power rails. Background: cream drafting sheet with faint measured grid. Illustrations remain generic; printed labels on the purchased modules win.

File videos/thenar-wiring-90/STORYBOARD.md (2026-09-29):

---
mode: autonomous
message: "One ESP32 reads the leader; the Pi 4B controls the follower PCA9685 directly over I²C."
audience: Thenar arm builder
duration: 90
---

## Changes from v1 — 2026-09-29

User note: "u not doing it clearly dude please.." The screenshot shows the all-at-once board diagram scaled down until connector labels are too small to follow. Replace the diagram as the focal content with six large-print, one-connection-at-a-time close-ups at the same 0/8/25/38/56/72-second beats. Keep physical pin numbers, separate servo power, and the untested/software-gap warning visible. Do not represent these graphics as footage of the user's actual boards.

## Still open

The revised composition needs preview approval before final MP4 rendering and replacement of the public video.

## Frame 1

- status: animated
- src: index.html
- shape: one continuous connector-level wiring-bench illustration, no hard cuts
- motion: `svg-path-draw` for each physical wire; component opacity reveals; spring entrance for the final guarded-test cue
- beat: 0–8 s — one ESP32 only; Pi is host and PWM controller, not a servo supply
- beat: 8–25 s — six AS5600 sensors to TCA9548A channels 0–5; 3.3 V/GND and I²C
- beat: 25–38 s — mux to leader ESP32 GPIO21/22, then USB to Pi
- beat: 38–56 s — Pi physical pins 1/3/5/6/11 to PCA9685 VCC/SDA/SCL/GND/OE
- beat: 56–72 s — PCA9685 channels 0–5 to MG996R signals; separate fused 6 V rail and common GND
- beat: 72–90 s — power-off checks, leader-only monitor, new Pi direct-driver software requirement, servo calibration, guarded arming
- why: turn the missing electronics into a traceable, buildable connection order without overstating validation

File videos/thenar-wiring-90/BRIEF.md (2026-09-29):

---
workflow: general-video
flow: automation
storyboard: no
message: "Connect the passive encoder leader through one ESP32 to a Raspberry Pi 4B, then drive the MG996R follower through a Pi-connected PCA9685."
destination: website
aspect: 1920x1080
language: en
audience: Thenar arm builder
length: 90s
---

## Intent

A practical, connector-level connection walkthrough for the existing Thenar leader and follower. The user has only one ESP32 and explicitly wants it on the encoder leader; a Raspberry Pi 4B must talk to that ESP32 over one USB data cable and control the follower PCA9685 over its own I²C header. This is an animated depiction of physical connectors and leads, not footage of the user's actual boards.

## Notes

- Show six AS5600 leader encoders, TCA9548A mux, the only ESP32, Pi 4B 40-pin header, PCA9685, six MG996R servos, and separate regulated 6 V servo power.
- Show physical Pi header pin numbers: 1=3V3, 3=GPIO2/SDA, 5=GPIO3/SCL, 6=GND, 11=GPIO17/OE. Depict functional terminals, not a claim that every vendor's board has identical physical pin placement.
- Never imply Pi USB/5 V or ESP32 3V3 powers the motors. Show common ground, fuse/cutoff, 6 V switch kept off during boot, and power-off wiring order.
- End with leader-only monitor mode, then a Pi-side follower driver, physical servo calibration and one unloaded servo before any full follower arming. Current `firmware/bridge.py` still assumes a second ESP32; the one-ESP32 plan is not a completed hardware test.
- Use clear silent on-screen instructional text; no invented voice or music.

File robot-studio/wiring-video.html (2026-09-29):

# Connect the two arms

One leader ESP32 → Raspberry Pi 4B → PCA9685 → MG996R follower. Six large-print connection steps in 90 seconds.

Your browser cannot play the video. Download the MP4 instead.

Illustrated wiring, not a physical test report. Check your actual board labels and keep servo power separate from Pi power. The current bridge software still expects a second ESP32; a Pi-side PCA9685 driver is required before this arrangement can move the follower. Read the exact pin table and bring-up order. (https://github.com/nickthelegend/thenar-arms/blob/main/so101-mg996r/RASPBERRY-PI-DIRECT-FOLLOWER.md) The video has on-screen instructions and no audio.

Download MP4 ↓

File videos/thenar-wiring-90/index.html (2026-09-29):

THENAR / LARGE-PRINT WIRING / 03

# ONE ESP32. ONE PI. TWO ARMS.

Encoder leader → ESP32 → USB → Pi 4B → PCA9685 → MG996R follower

ILLUSTRATED WIRING · NOT A HARDWARE TESTMatch the printed pin labels on your actual boards before applying power.

01

## One ESP32. One Pi. Two arms.

CONNECTION MAP

Leader arm6 × AS5600 encoders

→

ESP32reads leader only

→

Pi 4BUSB data from ESP32

→

Follower armPi → PCA9685 → servos

Do not power MG996R servos from the Pi. The follower needs a separate regulated 6 V supply.

02

## Each leader encoder gets its own mux channel.

LEADER ARM

AS5600 on joint | | TCA9548A channel
Base | → | CH0 SDA + SCL
Shoulder | → | CH1 SDA + SCL
Elbow | → | CH2 SDA + SCL
Wrist pitch | → | CH3 SDA + SCL
Wrist roll | → | CH4 SDA + SCL
Gripper | → | CH5 SDA + SCL

All six sensors also share 3V3 and GND. One AS5600 per channel, because each uses address 0x36.

03

## Mux → leader ESP32 → Pi USB.

DATA PATH

TCA9548A upstream | | ESP32 pin
SDA | → | GPIO21
SCL | → | GPIO22
VCC / VIN (3.3 V side) | → | 3V3 — verify module label
GND | → | GND

Then connect the ESP32 USB port to a Pi USB-A port with a data cable. This is leader data, not servo power.

04

## Pi header → PCA9685 logic pins.

PHYSICAL PIN NUMBERS

Raspberry Pi 4B header | | PCA9685 label
Pin 1 · 3V3 | → | VCC (logic only)
Pin 6 · GND | → | GND
Pin 3 · GPIO2 / SDA | → | SDA
Pin 5 · GPIO3 / SCL | → | SCL
Pin 11 · GPIO17 | → | OE, only if exposed

VCC is not V+. OE HIGH disables PWM, but OE is not an emergency stop.

05

## PCA9685 signals → MG996R servos.

FOLLOWER ARM

### Signal leads

PCA outputs CH0–CH5 go to the six servo signal wires, one joint per channel. Match signal, + and − markings on your actual board.

### Servo power

Separate regulated 6 V + goes through a fuse and switch to servo V+. Its − goes to servo GND. Pi and servo grounds share a reference.

Never connect the 6 V positive rail to Pi 5 V, Pi 3V3, or PCA9685 VCC.

06

## Power-off checks before a first motion test.

NOT YET HARDWARE-TESTED

1Leave the 6 V servo rail OFF. Check polarity and shorts.

2Power Pi separately; confirm all six leader readings.

3Confirm PCA9685 at I²C address 0x40.

4Calibrate and test one unloaded servo first.

Software gap: current bridge.py expects a second ESP32. A safe Pi-side PCA9685 driver is still required.

01

## Use only one ESP32.

It reads the leader. The Pi reads USB data and controls the follower over I²C.

The Pi GPIO does not power or directly pulse six servos.

02

## Connect six leader sensors.

AS5600 SDA/SCL pairs go to mux channels 0–5; share 3V3 and GND.

Each AS5600 uses address 0x36; the TCA9548A isolates the six copies.

03

## Plug the leader into the Pi.

Mux SDA → ESP32 GPIO21; SCL → GPIO22. Use one USB data cable.

The ESP32 runs leader firmware only. Pi USB-A is data, not servo power.

04

## Wire Pi header to PCA9685.

Physical pins 1, 6, 3, 5, 11 → VCC, GND, SDA, SCL, OE.

GPIO17/OE HIGH disables PWM. Keep 6V OFF until the Pi program is ready.

05

## Connect servo leads and 6V.

PCA channels 0–5 → six servo plugs. External 6V → V+ and GND.

Common ground. Check plug polarity and the board’s current rating; fuse and switch the rail.

06

## Test one unloaded joint first.

Monitor the leader, calibrate pulses, then test a single servo before all six.

Current bridge.py expects a second ESP32; a Pi-side PCA9685 driver is required.

THENAR · ONE-ESP WIRING

00:00 / 01:30

Illustrated pin maps · actual board silkscreens and servo pinout take precedence · no physical validation claimed

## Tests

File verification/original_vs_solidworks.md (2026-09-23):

# Original versus SolidWorks

The accepted follower reconstruction preserves the current modified R3 revision. Stock upstream STEP files describe a different revision and were not substituted for it. The source dimension register is in ../docs/source_audit.md. Native servo/horn sketches reproduce the nominal project primitives; custom printed geometry remains imported solid base features with native joint datums, not recovered manufacturing feature histories.

All 11 solid bodies in nine unique follower components report zero SolidWorks kernel faults. The forearm uses three closed, nonoverlapping solid partitions in one rigid part; its source seam prevents a successful native single-body union. Its original failed surface is suppressed and retained for traceability.

Printed exterior comparison includes all mesh vertices and 30,000 surface samples in each direction (50,000 for the forearm). Largest observed exterior discrepancy is 0.001958407 mm on the base; wrist reaches 0.001701408 mm. Both miss the stricter 0.001 mm trial check. All seven fit the 0.005 mm simplification tolerance used by the source generator. The forearm exterior comparison is below 0.000272 mm. These are bounded sampled comparisons, not mathematical identity claims. See printed_surface_comparison.json and ../solidworks/evidence/Forearm_seam_comparison.json.

All 19 component transforms were measured after native mate solving in 28 poses: each joint minimum, zero, maximum and return, plus HOME and a multi-joint pose. Maximum component-position difference from source forward kinematics is below 0.000001 mm; maximum orientation difference below 0.000001 degree. Joint axis origins remain within 0.000001 mm. Datum sketch endpoints were read back within 1e-11 m. Saved ZERO, HOME and MID_RANGE configurations were independently read back and passed.

This checks link spacing, joint locations, axes, signs, servo and horn placements, and gripper motion through the recorded poses. Detailed holes and interfaces are covered by exterior sampling and the source dimension register; they have not all been reverse-dimensioned into editable sketches. The six native hinge chains contain axis-collinearity and axial-location mates, with source limit-angle mates; twelve hardware lock mates attach hardware to its correct rigid group. Only the base is grounded.

Native SolidWorks HOME interference and 15 independent CAD-mesh pose checks report the six source-intended shaft/horn engagements, approximately 9.032 mm3 each. No other sampled internal overlap exceeds the source 0.5 mm3 threshold. J2_MAX and J3_MAX at other joints zero penetrate the tabletop. Discrete sampling does not certify swept or physical motion.

URDF/Xacro passes parsing, connected-tree, units/path and 28-pose comparison checks. MuJoCo URDF-import forward kinematics also passes all 28 poses. Its automatically inferred masses are rejected. Physical mass, COM, inertia, actuator/contact data and validated convex print proxies remain incomplete. ROS 2 visualization and Isaac import were not run in this environment.

Direct API drag probes failed and were discarded; HOME was rebuilt from a valid ZERO configuration and all saved configurations reverified. Manual use should currently rely on named configurations and native mate-angle controls. Mouse-drag behavior remains unverified.

## Leader L1 adopted geometry

All 18 adopted native-file exports pass their recorded comparison gates. Largest sampled bidirectional source/CAD discrepancy is 0.003381282 mm; individual bounds, volumes and stricter 1 µm checks are in `leader_geometry_comparison.json`. There are 25 healthy solid bodies across the unique components and 11 healthy source-artifact surface bodies. Base/forearm solid partitions and the 0.00001 mm forearm internal separation are disclosed numerical preservation measures.

The separate leader master contains 73 instances, one fixed base and 90 total native mates (84 active in FREE_MOTION). All 28 measured poses pass, maximum component position difference 5.80356045e-07 mm and orientation difference 3.86665823e-10 degrees. All three stored configurations pass final readback. The same six logical joints map through six AS5600 channels to the follower, with the source 14 mm wrist extension and +15 degree trigger mesh index retained.

Current leader volumetric collision checks use actual individually exported CAD solid bodies at 15 measured poses. Their pairwise results and table penetrations are in `leader_cad_mesh_motion_interference.json`; source zero-thickness surfaces are excluded only from solid-volume intersections. The inherited source 72-pose report remains separate. These are discrete checks, not collision-free swept-motion certification.

Both assembly constraint graphs calculate six independent rotations at HOME, with no additional infinitesimal freedom. This is a mathematical topology check, not freehand-drag verification. Failed drag/direct-dimension trials are rejected evidence. See `../docs/final_report.md` for the complete acceptance scope.

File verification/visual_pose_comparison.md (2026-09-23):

# Canonical visual pose comparison

Native SolidWorks views and MuJoCo URDF visual renders use the same five joint vectors. Camera framing, material shading and scene origins differ; these are visual orientation/silhouette checks, not a pixel-equality test. All 19 component transforms are checked numerically in each captured CAD pose; the full 28-pose URDF/MuJoCo regressions are recorded separately. MuJoCo uses forward kinematics only. Inferred physical masses are rejected and no dynamics stepping is claimed.

## ZERO

Joint degrees: [0, 0, 0, 0, 0, 0]. Native CAD/source position discrepancy: 1.29614459e-09 mm.

SolidWorks:

SolidWorks ZERO

MuJoCo visual geometry:

MuJoCo ZERO

## J1_MAX

Joint degrees: [85, 0, 0, 0, 0, 0]. Native CAD/source position discrepancy: 2.31808751e-09 mm.

SolidWorks:

SolidWorks J1_MAX

MuJoCo visual geometry:

MuJoCo J1_MAX

## J2_MIN

Joint degrees: [0, -80, 0, 0, 0, 0]. Native CAD/source position discrepancy: 2.22399225e-09 mm.

SolidWorks:

SolidWorks J2_MIN

MuJoCo visual geometry:

MuJoCo J2_MIN

## MULTI

Joint degrees: [20, -30, 40, -20, 30, 25]. Native CAD/source position discrepancy: 1.30281808e-09 mm.

SolidWorks:

SolidWorks MULTI

MuJoCo visual geometry:

MuJoCo MULTI

## HOME

Joint degrees: [0, -25, 35, 0, 0, 20]. Native CAD/source position discrepancy: 1.14827369e-09 mm.

SolidWorks:

SolidWorks HOME

MuJoCo visual geometry:

MuJoCo HOME

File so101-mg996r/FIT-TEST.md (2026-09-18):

# Print this first — unpowered MG996R fit test R1

**Do not print the entire arm.** This checks your purchased MG996R and tabs against
nominal dimensions. It does not validate motion, strength, payload or bearings.

## Files

- output/fit-test-r1/P1S_QUICK_GAUGES_ONLY.3mf: fast first print, two gauges.
- output/fit-test-r1/P1S_FIT_TEST_ONLY.3mf: wrist-holder prototype plus those gauges.
- Individual STL and editable STEP files are in the same folder.
- BENCH_FIT_ASSEMBLY.step: nominal servo inserted into holder, reference only.
- MG996R_REFERENCE_DO_NOT_PRINT.stl: purchased hardware envelope, do not print.
- verification.json: exported-mesh, nominal fit and slicing checks.

These plates are alternatives/stages, not two required full plates. Print the quick
gauges first. If they fit, remove the already printed gauges from the full 3MF and
print just the holder, retaining its supplied orientation. Scale stays **100%**.

## P1S setup and estimates

Sliced for P1S **0.4 mm nozzle**, Generic PETG, Textured PEI, 0.20 mm layers,
4 walls, 25% gyroid, automatic normal supports and 5 mm outer brim. Open the 3MF
in Bambu Studio, confirm your actual filament/printer/nozzle, inspect supports in
layer view and re-slice before sending. Do not send these profiles to a differently
configured printer.

Approximately **18 minutes / 5 g** for gauges; **1 hour 28 minutes / 24 g** for the
full test plate. Exact current estimates are in verification.json. Physical results
vary. All three parts fit one plate, clear of the front-left exclusion region.
This is not a claim of global minimum print time.

## What changed in the holder

The starting solid is the exact Motor_holder_SO101_Wrist.step. Original shape is
retained where possible. Added local material makes the two tab supports; body
opening has **0.30 mm nominal clearance per side**. Four elongated M3-clearance
slots allow small adjustment around assumed 49.5 × 10 mm hole centres. The tab
seating plane retains the nominal shaft datum. Underside bores provide nut access.
An approximately 16.34 mm³ severed shaving from the old cavity was deliberately
removed. The result is one valid solid and one watertight STL.

**BENCH ONLY:** it has not passed full-arm fit/collision checks. Its original
opposite-side support interface is still unconverted.

## Unpowered test procedure

1. Disconnect the servo completely. Remove the retaining screw and lift off its
   horn without forcing the shaft. Keep the original screw.
2. Deburr the gauge and remove brim/support residue. Do not enlarge it to turn a
   failed fit into a pass. Record any sanding separately.
3. Pass the body through the rectangular gauge until tabs rest on it. Check body,
   four hole locations and wire exit. The 41.5 × 20.6 mm opening tests the body
   section, not shaft height.
4. If it fails, stop; measure the obstruction, body and tab pitch. Do not force it
   or print the holder yet.
5. If it passes, insert the servo into the holder from the open tab side, horn
   removed, cable clear. It should insert and remove without force.
6. Try four M3 × 12 screws, washers and nuts only if actual tab holes accept M3.
   Tighten only enough to seat tabs: no crushing or visible flange bending.
   Confirm nut access and that screw tips do not contact the case.
7. The optional round gauge has four Ø3.4 mm holes on a 14 mm pitch circle for
   the proposed disc horn. A different supplied horn does not mean a bad servo;
   report its actual pattern so the interface can be adapted.
8. Photograph above, both ends and wire-exit side with a ruler/caliper visible.
   Return measurements below. **Do not power this prototype or attach arm links.**
   Powered travel follows complete mechanical interfaces and safe stops.

## Measurements to return

| Measurement | Nominal used / actual to fill |
|---|---|
| Case L × W × H, excluding shaft | 40.9 × 20 × 37 mm / ______ |
| Tab end-to-end span | 54 mm / ______ |
| Tab thickness | 2.6 mm assumed / ______ |
| Case bottom to tab underside | 26.8 mm assumed / ______ |
| Tab hole pitch, long × short axes | 49.5 × 10 mm assumed / ______ |
| Tab hole diameter | Must accept selected screw / ______ |
| Shaft centre from nearest case end | 10 mm assumed / ______ |
| Case bottom to fitted horn link-contact face | 47.2 mm assumed / ______ |
| Supplied horn diameter, holes, pitch, thickness | Unconfirmed / ______ |
| Gauge fit without sanding | pass / tight / loose / fails |
| Insertion, cable, screw/nut access | pass / obstruction location ______ |

Your reported 180° travel is recorded. The preview's ±80–85° ranges are not a
physical calibration. After mechanical approval, establish centre and safe
endpoints unloaded; do not start by commanding the advertised endpoints.

## Checks passed and limits

The holder is one valid BREP solid; all three printable STLs are single watertight
positive-volume shells. Exact intersection with the **nominal** servo is zero.
The defined top insertion envelope and four underside nut-access bores are clear.
Both alternative plates slice successfully with the stated profile.

These checks are not measurements of your hardware, structural analysis,
assembly-wide motion testing or a physical print/bench test. See BOM.md for
test hardware and the provisional follower/leader shopping list.

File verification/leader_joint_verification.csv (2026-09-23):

Joint | Parent | Child | Axis | Minimum | Maximum | Zero | Movement PASS/FAIL | Axis PASS/FAIL | Collision result | Mate result | Evidence | Notes
shoulder_pan | base_link | shoulder_link | local +Z | -85 | 85 | 0 | PASS | PASS | MIN: 0 overlaps >0.5mm3, 0 table penetrations; MAX: 0 overlaps >0.5mm3, 0 table penetrations; discrete checks only; raw smaller overlaps retained | PASS | solidworks/evidence/leader_joint_motion_measurements.json; verification/leader_cad_mesh_motion_interference.json | Mate-driven articulation only; physical ranges/calibration and mouse dragging unverified
shoulder_lift | shoulder_link | upper_arm_link | local +Z | -80 | 80 | 0 | PASS | PASS | MIN: 0 overlaps >0.5mm3, 0 table penetrations; MAX: 0 overlaps >0.5mm3, 37 table penetrations; discrete checks only; raw smaller overlaps retained | PASS | solidworks/evidence/leader_joint_motion_measurements.json; verification/leader_cad_mesh_motion_interference.json | Mate-driven articulation only; physical ranges/calibration and mouse dragging unverified
elbow_flex | upper_arm_link | lower_arm_link | local +Z | -80 | 80 | 0 | PASS | PASS | MIN: 0 overlaps >0.5mm3, 0 table penetrations; MAX: 0 overlaps >0.5mm3, 9 table penetrations; discrete checks only; raw smaller overlaps retained | PASS | solidworks/evidence/leader_joint_motion_measurements.json; verification/leader_cad_mesh_motion_interference.json | Mate-driven articulation only; physical ranges/calibration and mouse dragging unverified
wrist_flex | lower_arm_link | wrist_link | local +Z | -80 | 80 | 0 | PASS | PASS | MIN: 0 overlaps >0.5mm3, 0 table penetrations; MAX: 0 overlaps >0.5mm3, 0 table penetrations; discrete checks only; raw smaller overlaps retained | PASS | solidworks/evidence/leader_joint_motion_measurements.json; verification/leader_cad_mesh_motion_interference.json | Mate-driven articulation only; physical ranges/calibration and mouse dragging unverified
wrist_roll | wrist_link | gripper_link | local +Z | -85 | 85 | 0 | PASS | PASS | MIN: 0 overlaps >0.5mm3, 0 table penetrations; MAX: 0 overlaps >0.5mm3, 0 table penetrations; discrete checks only; raw smaller overlaps retained | PASS | solidworks/evidence/leader_joint_motion_measurements.json; verification/leader_cad_mesh_motion_interference.json | Mate-driven articulation only; physical ranges/calibration and mouse dragging unverified
gripper | gripper_link | moving_jaw_so101_v1_link | local +Z | 0 | 70 | 0 | PASS | PASS | MIN: 0 overlaps >0.5mm3, 0 table penetrations; MAX: 0 overlaps >0.5mm3, 0 table penetrations; discrete checks only; raw smaller overlaps retained | PASS | solidworks/evidence/leader_joint_motion_measurements.json; verification/leader_cad_mesh_motion_interference.json | Mate-driven articulation only; physical ranges/calibration and mouse dragging unverified

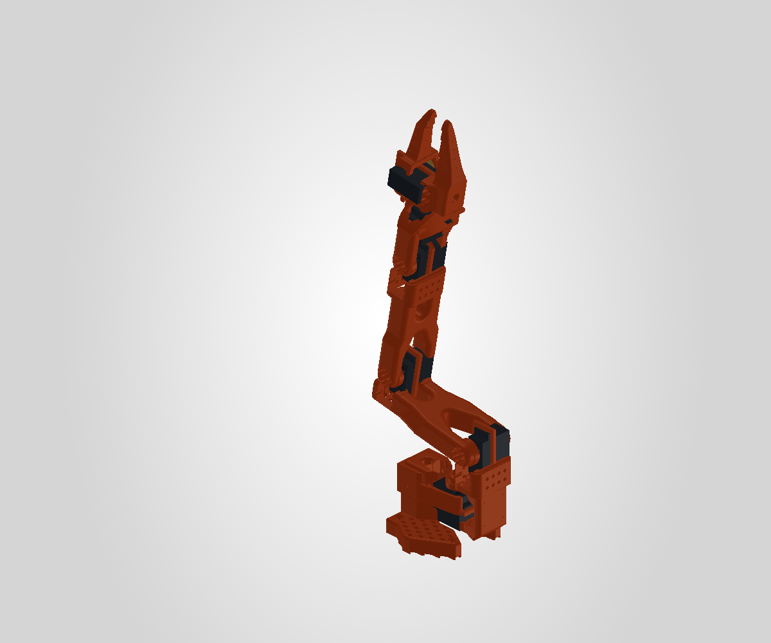
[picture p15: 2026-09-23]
verification/pose_images/solidworks_J2_MIN.bmp

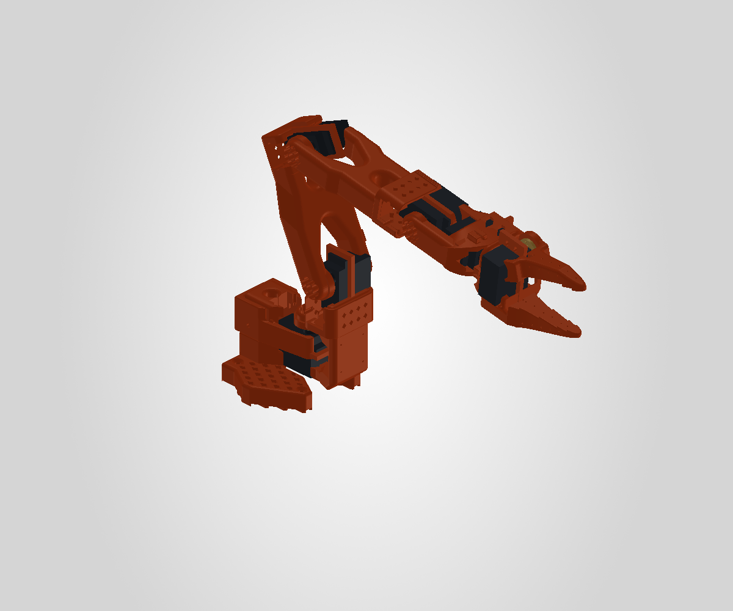
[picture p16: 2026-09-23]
verification/pose_images/solidworks_HOME.png

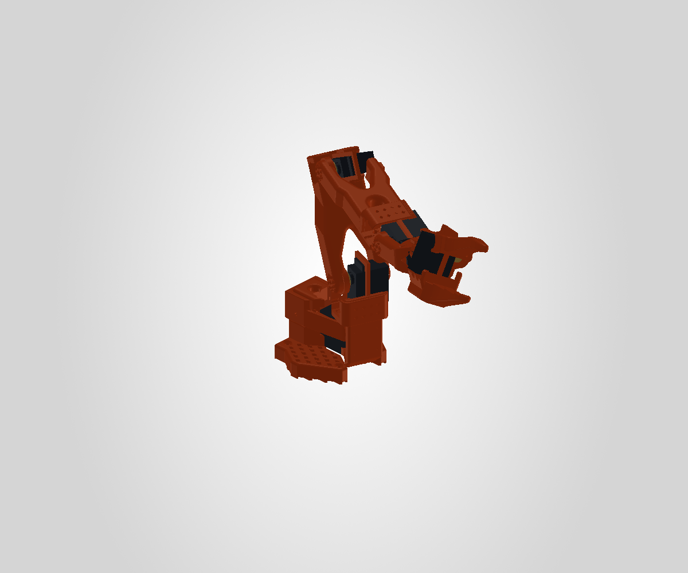
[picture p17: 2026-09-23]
verification/pose_images/solidworks_MULTI.png

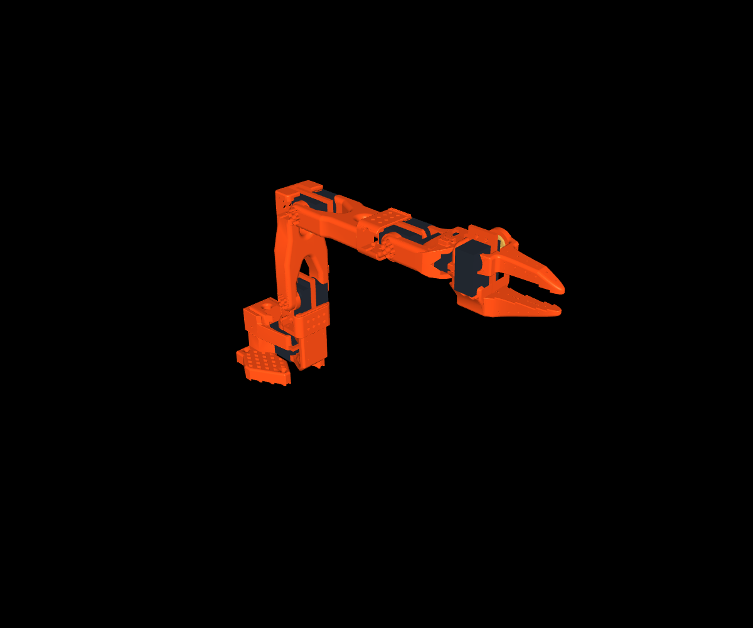
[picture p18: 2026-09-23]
verification/pose_images/mujoco_ZERO.png

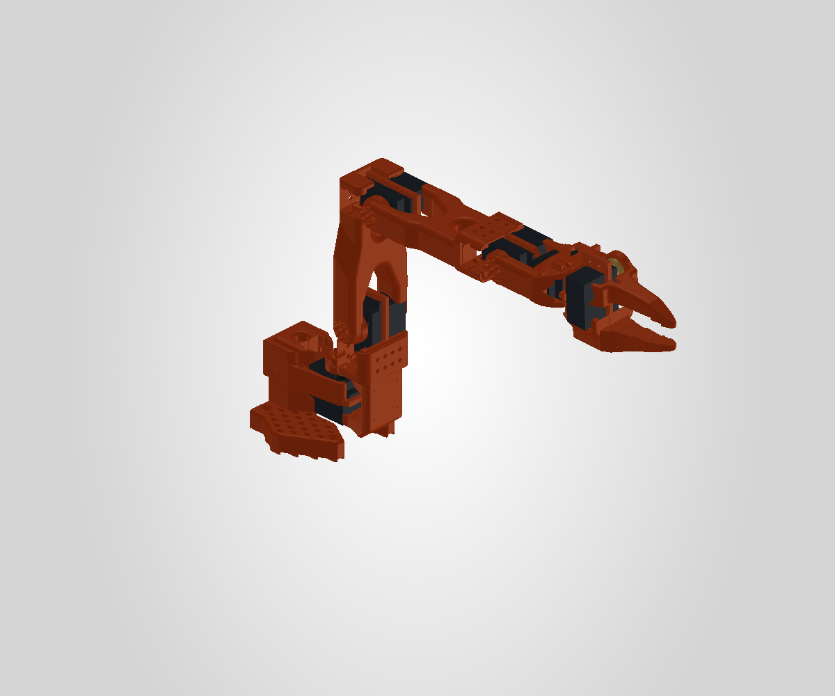
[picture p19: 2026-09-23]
verification/pose_images/solidworks_ZERO.bmp

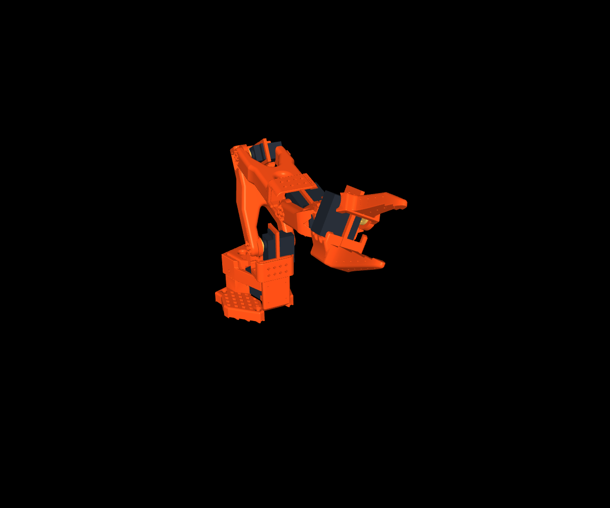
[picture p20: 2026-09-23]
verification/pose_images/mujoco_MULTI.png

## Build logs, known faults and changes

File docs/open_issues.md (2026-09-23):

# Open issues and evidence boundaries

- Custom prints mostly preserve imported solid base geometry with native joint datums; fully parametric manufacturing feature histories were not recovered. Stock STEP is a different revision.
- The follower forearm has three solids; the leader base/forearm each have four. The leader forearm has a disclosed 0.00001 mm internal gap. Eleven native sheets retain zero-thickness source artifacts. Their physical manufacturing interpretation is unverified.
- Follower base and wrist pass the source 0.005 mm tolerance but fail the stricter 0.001 mm surface trial. Surface comparisons are sampled checks, not mathematical identity proofs. Leader per-part results are recorded separately.
- Accepted movement uses native mate solving and stored configurations. Failed follower drag and leader direct-dimension trials are rejected evidence. Free mouse dragging remains unverified. Use configurations and native mate controls.
- Calculated six-DOF constraint rank is not a SolidWorks kernel mobility diagnostic. Controlled native joint movement is separately measured.
- Software bounds do not establish physical stops or collision-free motion. Follower J2_MAX/J3_MAX and inherited leader poses penetrate the tabletop. Current discrete CAD checks and original L1 checks are distinct. Cables, swept clearance and physical fits remain unverified.
- Published assemblies omit spatial placement of some BOM fasteners and retention details. No unsupported screw placement, internal electronics or physical thickness was invented.
- Actual masses, COM, inertia, infill distribution, torque, speed, payload, backlash, friction, damping, compliance, contact, thermal and electrical behavior are unverified. Unit-density integrals are not physical material assignments. Generic servos are not verified genuine 55 g TowerPro units.
- Servo neutral/sign/horn indexing and AS5600 zero counts/sign/alignment/gap need physical calibration. Source defaults and HOME zero-capture conversion are documented, not physically validated.
- Concave print collision meshes are retained; accepted convex dynamic-contact proxies are outstanding. Servo primitive proxies were checked separately.
- Xacro/parser and MuJoCo forward kinematics are tested; physical dynamics are not. The MJCF template intentionally rejects loading without real inertias. ROS 2 build/RViz and Isaac import/USD were not run because their tools were not found in the accessible environment.
- Faceted CAD is memory intensive. Open one robot master at a time when memory is limited; preserve checkpoints before trying repairs or mate changes.

Engineering prototypes: not physically tested or payload rated. See final_report.md for quantitative results and physical validation requirements.

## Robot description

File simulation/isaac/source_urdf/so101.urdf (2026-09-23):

<?xml version='1.0' encoding='utf-8'?>
<robot name="so101_mg996r_follower_r3">
  
  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
  <link name="base_link">
    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
  </link>
  <link name="shoulder_link">
    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
  </link>
  <link name="upper_arm_link">
    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
  </link>
  <link name="lower_arm_link">
    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
  </link>
  <link name="wrist_link">
    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
  </link>
  <link name="gripper_link">
    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
  </link>
  <link name="moving_jaw_so101_v1_link">
    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
  </link>
  <joint name="shoulder_pan" type="revolute">
    <parent link="base_link" />
    <child link="shoulder_link" />
    <origin xyz="0.0388353 -8.97657000000347e-09 0.0624" rpy="-3.14159265358305 0 -3.14159265358979" />
    <axis xyz="0 0 1" />
    <limit lower="-1.4835298641951802" upper="1.4835298641951802" effort="0" velocity="0.17453292519943295" />
  </joint>
  <joint name="shoulder_lift" type="revolute">
    <parent link="shoulder_link" />
    <child link="upper_arm_link" />
    <origin xyz="-0.0303992 -0.0182778 -0.0542" rpy="-1.5707963267949 -1.5707963267949 0" />
    <axis xyz="0 0 1" />
    <limit lower="-1.3962634015954636" upper="1.3962634015954636" effort="0" velocity="0.17453292519943295" />
  </joint>
  <joint name="elbow_flex" type="revolute">
    <parent link="upper_arm_link" />
    <child link="lower_arm_link" />
    <origin xyz="-0.11257 -0.028 3.5527136788005e-18" rpy="2.22044604925031e-16 0 1.5707963267949" />
    <axis xyz="0 0 1" />
    <limit lower="-1.3962634015954636" upper="1.3962634015954636" effort="0" velocity="0.17453292519943295" />
  </joint>
  <joint name="wrist_flex" type="revolute">
    <parent link="lower_arm_link" />
    <child link="wrist_link" />
    <origin xyz="-0.1349 0.00519999999999999 -1.06581410364015e-17" rpy="2.22044604925031e-16 0 -1.5707963267949" />
    <axis xyz="0 0 1" />
    <limit lower="-1.3962634015954636" upper="1.3962634015954636" effort="0" velocity="0.17453292519943295" />
  </joint>
  <joint name="wrist_roll" type="revolute">
    <parent link="wrist_link" />
    <child link="gripper_link" />
    <origin xyz="1.13686837721616e-16 -0.0691 0.0181" rpy="1.5707963267949 0.0486794999899367 3.14159265358979" />
    <axis xyz="0 0 1" />
    <limit lower="-1.4835298641951802" upper="1.4835298641951802" effort="0" velocity="0.17453292519943295" />
  </joint>
  <joint name="gripper" type="revolute">
    <parent link="gripper_link" />
    <child link="moving_jaw_so101_v1_link" />
    <origin xyz="0.0202 0.0188 -0.0234" rpy="1.5707963267949 0 0" />
    <axis xyz="0 0 1" />
    <limit lower="0.0" upper="1.2217304763960306" effort="0" velocity="0.17453292519943295" />
  </joint>
  <link name="gripper_frame_link" />
  <joint name="gripper_tool_fixed" type="fixed">
    <parent link="gripper_link" />
    <child link="gripper_frame_link" />
    <origin xyz="-0.0079 -0.000218121 -0.0981274" rpy="3.14159265358979 0 3.14159265358979" />
  </joint>
</robot>

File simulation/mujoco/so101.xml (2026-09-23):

<?xml version='1.0' encoding='utf-8'?>
<mujoco model="so101_structural_template_PHYSICS_BLOCKED">
  <!-- PHYSICS BLOCKED: insert measured link inertials before loading. inertiafromgeom=false deliberately prevents silent invented masses. See README.md and ../inertial_properties.yaml. -->
  <compiler angle="radian" meshdir="meshes" inertiafromgeom="false" />
  <asset>
    <mesh name="MG996R_Nominal_R3" file="MG996R_Nominal_R3.stl" />
    <mesh name="Base_MG996R_R3" file="Base_MG996R_R3.stl" />
    <mesh name="Shoulder_MG996R_R3" file="Shoulder_MG996R_R3.stl" />
    <mesh name="Metal_Horn_D20_PCD14_R3" file="Metal_Horn_D20_PCD14_R3.stl" />
    <mesh name="Upper_arm_MG996R_R3" file="Upper_arm_MG996R_R3.stl" />
    <mesh name="Forearm_MG996R_R3" file="Forearm_MG996R_R3.stl" />
    <mesh name="Wrist_pitch_roll_MG996R_R3" file="Wrist_pitch_roll_MG996R_R3.stl" />
    <mesh name="Gripper_body_MG996R_R3" file="Gripper_body_MG996R_R3.stl" />
    <mesh name="Moving_jaw_MG996R_R3" file="Moving_jaw_MG996R_R3.stl" />
  </asset>
  <worldbody>
    <body name="base_link">
      <!-- Physical inertial element intentionally absent: UNVERIFIED. -->
      <geom name="follower_sts3215_03a_v1_2" type="mesh" mesh="MG996R_Nominal_R3" pos="0.0263353 -8.97656999879322e-09 0.0437" quat="1 -4.15794949850208e-44 3.79822709827829e-65 -3.08148791101958e-33" contype="0" conaffinity="0" group="2" />
      <geom name="follower_Base_MG996R_R3" type="mesh" mesh="Base_MG996R_R3" pos="-0.00636471 -8.97657e-09 -0.0024" quat="0.500000000001687 0.499999999998313 0.500000000001687 0.499999999998313" contype="0" conaffinity="0" group="2" />
      <body name="shoulder_link" pos="0.0388353 -8.97657000000347e-09 0.0624" quat="2.06552080115807e-28 -6.12303176911189e-17 1 -3.37336286833877e-12">
        <joint name="shoulder_pan" type="hinge" axis="0 0 1" limited="true" range="-1.48352986419518 1.48352986419518" />
        <!-- Physical inertial element intentionally absent: UNVERIFIED. -->
        <geom name="follower_sts3215_03a_v1_4" type="mesh" mesh="MG996R_Nominal_R3" pos="-0.0303992 0.000422241000000002 -0.0417" quat="0.5 0.5 0.5 -0.5" contype="0" conaffinity="0" group="2" />
        <geom name="follower_Shoulder_MG996R_R3" type="mesh" mesh="Shoulder_MG996R_R3" pos="0.0122008 2.22413e-05 0.0464" quat="0.707106781186548 -0.707106781186547 -4.3530962547384e-33 -4.35309625467354e-33" contype="0" conaffinity="0" group="2" />
        <geom name="follower_metal_horn_0" type="mesh" mesh="Metal_Horn_D20_PCD14_R3" pos="0.0125 1.39964063017479e-18 0.0187" quat="-6.16297582203915e-33 -6.12303176911189e-17 1 6.12303176911189e-17" contype="0" conaffinity="0" group="2" />
        <body name="upper_arm_link" pos="-0.0303992 -0.0182778 -0.0542" quat="0.5 -0.5 -0.5 -0.5">
          <joint name="shoulder_lift" type="hinge" axis="0 0 1" limited="true" range="-1.39626340159546 1.39626340159546" />
          <!-- Physical inertial element intentionally absent: UNVERIFIED. -->
          <geom name="follower_sts3215_03a_v1_7" type="mesh" mesh="MG996R_Nominal_R3" pos="-0.11257 -0.0155 0.0187" quat="4.32963728535968e-17 0.707106781186548 -0.707106781186547 4.32963728535968e-17" contype="0" conaffinity="0" group="2" />
          <geom name="follower_Upper_arm_MG996R_R3" type="mesh" mesh="Upper_arm_MG996R_R3" pos="-0.065085 0.012 0.0182" quat="6.12303176911189e-17 1 0 0" contype="0" conaffinity="0" group="2" />
          <geom name="follower_metal_horn_1" type="mesh" mesh="Metal_Horn_D20_PCD14_R3" pos="0.0125 2.8421709430404e-17 0.018700041" quat="2.22044604925031e-16 6.12303176911189e-17 1 -6.12303176911189e-17" contype="0" conaffinity="0" group="2" />
          <body name="lower_arm_link" pos="-0.11257 -0.028 3.5527136788005e-18" quat="0.707106781186548 7.85046229341888e-17 7.85046229341887e-17 0.707106781186547">
            <joint name="elbow_flex" type="hinge" axis="0 0 1" limited="true" range="-1.39626340159546 1.39626340159546" />
            <!-- Physical inertial element intentionally absent: UNVERIFIED. -->
            <geom name="follower_sts3215_03a_v1_11" type="mesh" mesh="MG996R_Nominal_R3" pos="-0.1224 0.00519999999999996 0.0187" quat="-1.63015760731769e-32 -6.12303176911189e-17 1 -6.12303176911189e-17" contype="0" conaffinity="0" group="2" />
            <geom name="follower_Forearm_MG996R_R3" type="mesh" mesh="Forearm_MG996R_R3" pos="-0.0648499 -0.032 0.0182" quat="6.12303176911189e-17 1 1.68155815718978e-44 1.97419053915225e-39" contype="0" conaffinity="0" group="2" />
            <geom name="follower_metal_horn_2" type="mesh" mesh="Metal_Horn_D20_PCD14_R3" pos="0.0125 0 0.0186999999999998" quat="-7.91877026559471e-32 -2.8327492261615e-16 1 -2.8327492261615e-16" contype="0" conaffinity="0" group="2" />
            <body name="wrist_link" pos="-0.1349 0.00519999999999999 -1.06581410364015e-17" quat="0.707106781186548 7.85046229341888e-17 -7.85046229341887e-17 -0.707106781186547">
              <joint name="wrist_flex" type="hinge" axis="0 0 1" limited="true" range="-1.39626340159546 1.39626340159546" />
              <!-- Physical inertial element intentionally absent: UNVERIFIED. -->
              <geom name="follower_sts3215_03a_no_horn_v1_12" type="mesh" mesh="MG996R_Nominal_R3" pos="8.5265128291212e-17 -0.0504 0.0306" quat="0.5 0.5 0.5 -0.5" contype="0" conaffinity="0" group="2" />
              <geom name="follower_Wrist_pitch_roll_MG996R_R3" type="mesh" mesh="Wrist_pitch_roll_MG996R_R3" pos="0 -0.028 0.0181" quat="0.5 -0.5 -0.5 -0.5" contype="0" conaffinity="0" group="2" />
              <geom name="follower_metal_horn_3" type="mesh" mesh="Metal_Horn_D20_PCD14_R3" pos="0 0.0125 0.0187" quat="-4.32963728535968e-17 0.707106781186548 -0.707106781186547 -4.32963728535968e-17" contype="0" conaffinity="0" group="2" />
              <body name="gripper_link" pos="1.13686837721616e-16 -0.0691 0.0181" quat="0.0172091029770778 -0.0172091029770778 0.706897338214485 0.706897338214485">
                <joint name="wrist_roll" type="hinge" axis="0 0 1" limited="true" range="-1.48352986419518 1.48352986419518" />
                <!-- Physical inertial element intentionally absent: UNVERIFIED. -->
                <geom name="follower_sts3215_03a_v1_14" type="mesh" mesh="MG996R_Nominal_R3" pos="0.00769999999999999 0.000100000000000001 -0.0234" quat="0.707106781186548 -0.707106781186547 -7.87953377839742e-20 2.37447412890945e-18" contype="0" conaffinity="0" group="2" />
                <geom name="follower_Gripper_body_MG996R_R3" type="mesh" mesh="Gripper_body_MG996R_R3" pos="8.5265128291212e-17 -0.000218213999999998 0.000949705999999992" quat="-6.12303176911189e-17 1 1.73472347597681e-18 -9.24093221276131e-34" contype="0" conaffinity="0" group="2" />
                <geom name="follower_metal_horn_4" type="mesh" mesh="Metal_Horn_D20_PCD14_R3" pos="-0.000608253454377717 0.0124851923387362 0.0187" quat="-3.65905124752447e-16 0.724106441191563 -0.689688235237408 -3.48512933180878e-16" contype="0" conaffinity="0" group="2" />
                <body name="moving_jaw_so101_v1_link" pos="0.0202 0.0188 -0.0234" quat="0.707106781186548 0.707106781186547 0 0">
                  <joint name="gripper" type="hinge" axis="0 0 1" limited="true" range="0 1.22173047639603" />
                  <!-- Physical inertial element intentionally absent: UNVERIFIED. -->
                  <geom name="follower_Moving_jaw_MG996R_R3" type="mesh" mesh="Moving_jaw_MG996R_R3" pos="0 -5.6843418860808e-17 0.0189" quat="1 -1.11608871664749e-33 1.73472347597681e-18 -2.15727897140433e-33" contype="0" conaffinity="0" group="2" />
                  <geom name="follower_metal_horn_5" type="mesh" mesh="Metal_Horn_D20_PCD14_R3" pos="-0.0124999999999999 0 0.0187" quat="-2.8327492261615e-16 1 -4.5533341455196e-33 -1.73472347597681e-18" contype="0" conaffinity="0" group="2" />
                </body>
              </body>
            </body>
          </body>
        </body>
      </body>
    </body>
  </worldbody>
</mujoco>

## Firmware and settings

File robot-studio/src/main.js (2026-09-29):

import * as THREE from 'three';
import { OrbitControls } from 'three/addons/controls/OrbitControls.js';
import { STLLoader } from 'three/addons/loaders/STLLoader.js';
import { RoomEnvironment } from 'three/addons/environments/RoomEnvironment.js';
import { createIcons, icons } from 'lucide';
import './style.css';
import { clampJointAngles, applyJointAngles } from './kinematics.js';
import { frameBounds } from './view-layout.js';
import { addFitTestPlates } from './fit-test.js';
import { isR3, r3Notice, renderR3Plates, renderR3Checks, followerBelowTable } from './r3-ui.js';
import { createAssemblyGuard } from './assembly-guard.js';
import { encoderLinks, renderEncoderPlates, appendEncoderChecks } from './encoder-ui.js';
import { modelUrl, installModelLinkRewriter } from './asset-path.js';

const $=s=>document.querySelector(s);
installModelLinkRewriter();
const studyView=new URLSearchParams(location.search).get('geometry')!=='original';
const icon=name=>`<i data-lucide="${name}"></i>`;
$('#app').innerHTML=`
<header class="topbar"><div class="brand"><svg class="brandmark" viewBox="0 0 32 32" fill="none"><path d="M6 26h20M10 24l4-12 10-6M14 12l10 9" stroke="currentColor" stroke-width="2.5" stroke-linecap="round"/><circle cx="14" cy="12" r="3" fill="currentColor"/></svg>THENAR<small>ROBOT STUDIO</small></div><span class="rev">SO-101</span><div class="top-right"><span class="status-text">Original SO-101 · MG996R conversion pending</span><a class="download" href="/models/so101/SO101-originals.zip" download>${icon('download')}<span>Download original files</span></a></div></header>
<main class="workspace"><aside class="sidebar"><div class="side-head">Assembly explorer ${icon('layers')}</div><div class="side-section"><p class="side-label">VISIBLE ASSEMBLIES</p><button class="robot-button active" data-robot="both">${icon('boxes')}<span>Leader + follower<small>Original source geometry</small></span></button><button class="robot-button" data-robot="follower"><span class="robot-color"></span><span>Follower arm<small>Original STS3215 reference</small></span></button><button class="robot-button" data-robot="leader"><span class="robot-color leader"></span><span>SO-101 leader<small>Encoder conversion pending</small></span></button></div><div class="tree" id="tree"></div><div class="side-footer">Millimetres · exact source STLs<br>Actual CAD meshes in every view.</div></aside>
<nav class="tabs" aria-label="Workspace views"><button class="active" data-tab="assembly">${icon('box')}Assembly</button><button data-tab="plates">${icon('grid-2x2')}Print plates</button><button data-tab="checks">${icon('clipboard-check')}Parts & checks</button></nav>
<section class="canvas-wrap" aria-label="Interactive three-dimensional robot viewer"><div class="scene-title"><h1 id="scene-heading">The original SO-101.</h1><p id="scene-subtitle">Original meshes · MG996R fit not yet released</p></div><div class="view-tools"><button id="fit-view" title="Fit assembly" aria-label="Fit assembly">${icon('maximize')}</button><button id="front-view" title="Front view" aria-label="Front view">${icon('panel-top')}</button><button id="top-view" title="Top view" aria-label="Top view">${icon('square')}</button><button id="capture" title="Save view as PNG" aria-label="Save view as PNG">${icon('camera')}</button></div><div id="selected-tag" class="selected-tag hidden"></div><div class="legend"><span><b class="dot"></b>Follower</span><span><b class="dot blue"></b>Leader</span><span><b class="dot dark"></b>Purchased parts</span></div><span class="viewport-hint">Drag to orbit · Scroll to zoom</span><div class="loading" id="loading"><span id="load-label">Loading CAD assemblies…</span><progress value="0" max="100"></progress></div><div class="checks-view hidden" id="checks-view"></div></section>
<aside class="panel"><div class="panel-head" id="panel-heading">${icon('sliders-horizontal')} Joint controls</div><div class="panel-body" id="panel-body"></div></aside><footer class="footbar"><span id="footer-status">Preparing geometry</span><span>Geometric preview · no hardware connection</span></footer></main><div id="toast" class="toast hidden" role="status"></div>`;
$('.rev').outerHTML=`<select id="geometry-mode" aria-label="Geometry version" style="max-width:190px;background:#17253e;color:white;border:1px solid #738095;border-radius:4px;padding:7px"><option value="original">Original SO-101</option><option value="clearance">MG996R clearance study</option></select>`;
const filmLink=document.createElement('a');filmLink.className='film-link';filmLink.href='./assembly-video.html';filmLink.setAttribute('aria-label','Open 3D assembly video');filmLink.innerHTML='<span class="film-word">3D assembly film</span><span aria-hidden="true">▶</span>';$('.top-right').prepend(filmLink);
const wiringLink=document.createElement('a');wiringLink.className='film-link';wiringLink.href='./wiring-video.html';wiringLink.setAttribute('aria-label','Open Raspberry Pi wiring video');wiringLink.innerHTML='<span class="film-word">Wiring video</span><span aria-hidden="true">⚡</span>';$('.top-right').prepend(wiringLink);
$('#geometry-mode option[value="clearance"]').textContent='MG996R follower · R3';
$('#geometry-mode').value=studyView?'clearance':'original';$('#geometry-mode').onchange=e=>{location.search=e.target.value==='clearance'?'?geometry=clearance':'?geometry=original'};
if(studyView){$('.status-text').textContent='Loading MG996R follower R3…';$('[data-robot="follower"] small').textContent='Original-derived MG996R conversion';$('.top-right .download').href='/models/so101/follower-r3/SO101-MG996R-R3-PROTOTYPE.zip';$('.top-right .download span').textContent='Download MG996R R3'}
const refreshIcons=()=>createIcons({icons});refreshIcons();
let manifest,report,fitReport,benchReport,motionCheck,activeTab='assembly',activeRobot='both',selected=null,angles=[],explosion=0,animate=false,transparent=false,showHardware=true,plateIndex=0;
let scene,camera,renderer,orbit,robotGroup,plateGroup,floor,grid;
const nodeMap={},partMeshes=[],geometries=new Map(),partMap=new Map(),materialMap=new Map();
let animationStart=0,assemblyGuard=null;
function toast(msg){$('#toast').textContent=msg;$('#toast').classList.remove('hidden');clearTimeout(toast.timer);toast.timer=setTimeout(()=>$('#toast').classList.add('hidden'),3300)}
function material(p,robot){
 const key=p.id+robot;if(materialMap.has(key))return materialMap.get(key);
 let color=robot==='leader'?0x5585df:0xf2b845,metalness=.08,roughness=.48;
 if(p.kind==='hardware') {color=0x303848;roughness=.4;if(p.id.includes('bearing')||p.id.includes('horn')||p.id.includes('screw')){color=0xabb7c6;metalness=.8;roughness=.25}if(p.id.includes('pcb')||['esp32','pca9685','tca9548a'].includes(p.id))color=0x176f64;if(p.id.includes('magnet')){color=0x8d96a3;metalness=.85}}
 if(p.kind==='print'&&['servo_mount','encoder_mount','base','electronics_tray'].includes(p.id)){color=robot==='leader'?0x254570:0x304054}
 const mat=new THREE.MeshStandardMaterial({color,metalness,roughness});materialMap.set(key,mat);return mat;
}
function setupScene(){
 scene=new THREE.Scene();scene.background=new THREE.Color('#eef1f5');scene.fog=new THREE.Fog('#eef1f5',1800,4500);
 camera=new THREE.PerspectiveCamera(35,1,.5,8000);camera.up.set(0,0,1);camera.position.set(680,-1000,720);
 renderer=new THREE.WebGLRenderer({antialias:true,preserveDrawingBuffer:true});renderer.setPixelRatio(Math.min(devicePixelRatio,2));renderer.shadowMap.enabled=true;renderer.shadowMap.type=THREE.PCFSoftShadowMap;renderer.toneMapping=THREE.ACESFilmicToneMapping;renderer.toneMappingExposure=1.25;
 $('.canvas-wrap').prepend(renderer.domElement);renderer.domElement.setAttribute('aria-label','Robot CAD viewport. Use the joint controls to move both assemblies.');
 const pmrem=new THREE.PMREMGenerator(renderer);scene.environment=pmrem.fromScene(new RoomEnvironment(),.04).texture;pmrem.dispose();
 scene.add(new THREE.HemisphereLight(0xffffff,0x909cac,2));const sun=new THREE.DirectionalLight(0xffffff,3.2);sun.position.set(-300,-500,900);sun.castShadow=true;sun.shadow.mapSize.set(2048,2048);sun.shadow.camera.left=-700;sun.shadow.camera.right=700;sun.shadow.camera.top=700;sun.shadow.camera.bottom=-700;sun.shadow.camera.far=2000;sun.shadow.normalBias=.5;scene.add(sun);
 floor=new THREE.Mesh(new THREE.PlaneGeometry(6000,6000),new THREE.MeshStandardMaterial({color:0xe8edf3,roughness:.9}));floor.position.z=-1;floor.receiveShadow=true;scene.add(floor);
 grid=new THREE.GridHelper(1600,64,0xc3cddb,0xd8dfe8);grid.rotation.x=Math.PI/2;grid.position.z=-.6;grid.material.transparent=true;grid.material.opacity=.52;scene.add(grid);
 robotGroup=new THREE.Group();plateGroup=new THREE.Group();scene.add(robotGroup,plateGroup);plateGroup.visible=false;
 orbit=new OrbitControls(camera,renderer.domElement);orbit.enableDamping=true;orbit.dampingFactor=.075;orbit.target.set(0,0,150);orbit.maxPolarAngle=Math.PI*.49;orbit.minDistance=70;orbit.maxDistance=7000;
 new ResizeObserver(()=>{const el=$('.canvas-wrap');camera.aspect=el.clientWidth/el.clientHeight;camera.updateProjectionMatrix();renderer.setSize(el.clientWidth,el.clientHeight);if(manifest&&partMeshes.length&&activeTab!=='checks')fitView()}).observe($('.canvas-wrap'));
 let down;renderer.domElement.addEventListener('pointerdown',e=>down=[e.clientX,e.clientY]);renderer.domElement.addEventListener('pointerup',e=>{if(!down||Math.hypot(e.clientX-down[0],e.clientY-down[1])>4||activeTab!=='assembly')return;const b=renderer.domElement.getBoundingClientRect(),ray=new THREE.Raycaster();ray.setFromCamera(new THREE.Vector2((e.clientX-b.left)/b.width*2-1,-(e.clientY-b.top)/b.height*2+1),camera);const hit=ray.intersectObjects(partMeshes.filter(m=>m.visible&&nodeMap[m.userData.robot].visible),false)[0];if(hit)selectPart(hit.object.userData.part)});
 renderer.setAnimationLoop(t=>{if(animate&&activeTab==='assembly'){const s=(t-animationStart)/1000;const next=manifest.home.map((v,i)=>v+Math.sin(s*.65+i*.5)*[18,10,12,12,18,9][i]);if(!acceptPose(next))animate=false;syncSliders()}orbit.update();renderer.render(scene,camera)});
}
async function loadCAD(){
 const res=await fetch(modelUrl(studyView?'study-manifest.json':'manifest.json'));if(!res.ok)throw new Error('CAD manifest could not be loaded.');const manifestText=await res.text();manifest=JSON.parse(manifestText);angles=[...manifest.home];
 try {fitReport=await(await fetch(modelUrl('fit-analysis.json'))).json()}catch{fitReport=null}report=null;
 try {const r=await fetch(modelUrl('motion-verification.json'));if(r.ok){motionCheck=await r.json();if(studyView){const hash=Array.from(new Uint8Array(await crypto.subtle.digest('SHA-256',new TextEncoder().encode(manifestText)))).map(x=>x.toString(16).padStart(2,'0')).join('');if(hash!==motionCheck.manifest_sha256)motionCheck=null}}}catch{motionCheck=null}
 if(!isR3(manifest))try {const r=await fetch(modelUrl('fit-test/verification.json'));if(r.ok){benchReport=await r.json();addFitTestPlates(manifest,benchReport)}}catch{benchReport=null}
 if(isR3(manifest)){
  $('.status-text').textContent='MG996R follower R3 · nominal-fit prototype';
  $('.top-right .download').href='/models/so101/follower-r3/SO101-MG996R-R3-PROTOTYPE.zip';
  $('.top-right .download span').textContent='Download MG996R R3';
  $('[data-robot="follower"] small').textContent='7 converted printing units';
  $('[data-robot="both"] small').textContent='MG996R follower + stock leader';
  $('.side-footer').innerHTML='Millimetres · original-derived CAD<br>Nominal prototype · physical tests pending.';
 }
 if(manifest.encoder_leader){
  $('#geometry-mode option[value="clearance"]').textContent='MG996R + encoder leader';
  $('.status-text').textContent='MG996R follower + AS5600 encoder leader · prototypes';
  $('[data-robot="both"] small').textContent='Both converted assemblies';
  $('[data-robot="leader"] small').textContent='6 passive AS5600 encoder joints';
 }
 const loader=new STLLoader();let count=0;
 await Promise.all(manifest.parts.map(async p=>{partMap.set(p.id,p);const g=await loader.loadAsync(modelUrl(p.file));g.computeVertexNormals();geometries.set(p.id,g);$('progress').value=++count/manifest.parts.length*100}));
 for(const n of manifest.nodes){const g=new THREE.Group();g.position.fromArray(n.position);g.rotation.set(...n.rotation.map(THREE.MathUtils.degToRad));g.userData=n;nodeMap[n.id]=g;(n.parent?nodeMap[n.parent]:robotGroup).add(g)}
 for(const i of manifest.instances){const p=partMap.get(i.part),mesh=new THREE.Mesh(geometries.get(i.part),material(p,i.robot));mesh.position.fromArray(i.position);mesh.rotation.set(...i.rotation.map(THREE.MathUtils.degToRad));mesh.castShadow=true;mesh.receiveShadow=true;mesh.userData={...i,originalPosition:[...i.position]};nodeMap[i.node].add(mesh);partMeshes.push(mesh)}
 updatePose();if(manifest.encoder_leader)assemblyGuard=createAssemblyGuard(partMeshes);
 buildTree();showPanel();fitView();$('#loading').classList.add('hidden');filterRobot(activeRobot);$('#footer-status').textContent=`${manifest.instances.length} components · ${manifest.parts.filter(p=>p.kind==='print').length} print-part meshes · mm`;
 window.studio={manifest,scene,renderer,camera,partMeshes,nodeMap,motionCheck,get angles(){return angles},setAngles(v){const ok=acceptPose(v);syncSliders();return ok},get activeTab(){return activeTab},get activeRobot(){return activeRobot},get plateIndex(){return plateIndex},selectPart,tab,fitView};
 if(new URLSearchParams(location.search).get('view')==='fit-test')tab('plates');
}
function updatePose(){angles=applyJointAngles(manifest.nodes,nodeMap,angles,manifest.limits);scene.updateMatrixWorld(true)}
function acceptPose(next){
 const previous=[...angles];angles=clampJointAngles(next,manifest.limits);updatePose();
 if(assemblyGuard&&explosion===0){const hit=assemblyGuard();if(hit){angles=previous;updatePose();toast(`Pose blocked: ${hit.type==='table'?'table contact':hit.a+' / '+hit.b}`);return false;}}
 if(isR3(manifest)&&explosion===0&&followerBelowTable(partMeshes)){
  angles=previous;updatePose();toast('Pose blocked: the follower would enter the tabletop.');return false;
 }
 return true;
}
function fitView(direction){
 if(manifest?.encoder_leader&&activeTab==='assembly'){$('#scene-heading').textContent=activeRobot==='leader'?'AS5600 encoder leader · L1':activeRobot==='follower'?'MG996R follower · R3':'Follower + encoder leader';$('#scene-subtitle').textContent='Original-derived CAD · nominal prototypes · physical tests pending';}
 const group=activeTab==='plates'?plateGroup:robotGroup;const box=new THREE.Box3();group.traverse(o=>{if(o.isMesh&&o.visible){let ancestor=o.parent,visible=true;while(ancestor){if(!ancestor.visible)visible=false;ancestor=ancestor.parent}if(visible)box.expandByObject(o)}});
 frameBounds(camera,box,orbit.target,direction?.isVector3?direction:undefined);orbit.update();
}
function selectPart(id){selected=id;for(const m of partMeshes){if(!m.userData.baseMat)m.userData.baseMat=m.material;if(m.userData.part===id){m.material=m.userData.baseMat.clone();m.material.emissive.setHex(0x336dcc);m.material.emissiveIntensity=.26}else m.material=m.userData.baseMat;}document.querySelectorAll('.part-entry').forEach(e=>e.classList.toggle('active',e.dataset.part===id));$('#selected-tag').textContent=partMap.get(id).label;$('#selected-tag').classList.remove('hidden');if(activeTab==='assembly')showPanel()}
function buildTree(){
 const groups=isR3(manifest)?[
  {label:'Converted follower',kind:'print',open:true,parts:manifest.parts.filter(p=>p.kind==='print'&&p.quantity?.follower)},
  {label:manifest.encoder_leader?'Converted encoder leader':'Stock leader reference',kind:'print',open:false,parts:manifest.parts.filter(p=>p.kind==='print'&&p.quantity?.leader)},
  {label:'Purchased components',kind:'hardware',open:false,parts:manifest.parts.filter(p=>p.kind==='hardware')}
 ]:['print','hardware'].map(kind=>({label:kind==='print'?'Printed components':'Purchased components',kind,open:kind==='print',parts:manifest.parts.filter(p=>p.kind===kind)}));
 $('#tree').innerHTML=groups.map(g=>`<details ${g.open?'open':''}><summary>${g.label} <span style="color:#77869b">${g.parts.length}</span></summary>${g.parts.map(p=>`<button class="part-entry" data-part="${p.id}">${icon(g.kind==='print'?'box':'cpu')}<span>${p.label}</span></button>`).join('')}</details>`).join('');
 document.querySelectorAll('.part-entry').forEach(e=>e.onclick=()=>{tab('assembly');selectPart(e.dataset.part)});refreshIcons();
}
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

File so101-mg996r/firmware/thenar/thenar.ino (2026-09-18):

#include <Arduino.h>
#include <Wire.h>
#include <Preferences.h>
#include "model.h"
#include "calibration.h"
#ifndef ROLE_LEADER
#define ROLE_LEADER 1
#endif
constexpr uint8_t MUX=0x70,ENC=0x36,PCA=0x40;
constexpr int SDA_PIN=21,SCL_PIN=22,OE_PIN=25;
Preferences prefs;uint16_t zeros[6]={};int8_t signs[6]={1,1,1,1,1,1};
bool calibrated=false,armed=false,driverOK=false,haveTarget=false;
uint32_t tick=0,lastTarget=0;float goal[6],current[6];
char line[128];size_t used=0;bool overflow=false;uint8_t prescale;
bool writeReg(uint8_t addr,uint8_t reg,uint8_t value){Wire.beginTransmission(addr);Wire.write(reg);Wire.write(value);return Wire.endTransmission()==0;}
int readReg(uint8_t addr,uint8_t reg){Wire.beginTransmission(addr);Wire.write(reg);if(Wire.endTransmission(false))return -1;if(Wire.requestFrom(addr,uint8_t(1))!=1)return -1;return Wire.read();}
void stop(const char *why){digitalWrite(OE_PIN,HIGH);armed=false;haveTarget=false;Serial.print("STOP ");Serial.println(why);}
bool encoder(int channel,uint16_t &raw){
 Wire.beginTransmission(MUX);Wire.write(uint8_t(1<<channel));if(Wire.endTransmission())return false;
 int s=readReg(ENC,0x0B);if(s<0||!(s&0x20)||(s&0x18))return false;
 Wire.beginTransmission(ENC);Wire.write(0x0C);if(Wire.endTransmission(false))return false;
 if(Wire.requestFrom(ENC,uint8_t(2))!=2)return false;raw=((Wire.read()&15)<<8)|Wire.read();return true;
}
bool sample(uint16_t *raw){for(int i=0;i<6;i++)if(!encoder(i,raw[i])){Serial.print("FAULT encoder ");Serial.println(i);return false;}return true;}
bool validPulse(int i,float q){float p=model::pulse(q,SERVO_ZERO_US[i],US_PER_DEGREE[i],SERVO_SIGN[i]);return isfinite(p)&&p>=PULSE_MIN_US[i]&&p<=PULSE_MAX_US[i];}
bool servo(int i,float q){
 if(!validPulse(i,q))return false;float us=model::pulse(q,SERVO_ZERO_US[i],US_PER_DEGREE[i],SERVO_SIGN[i]);
 uint16_t count=lroundf(us*PCA_CLOCK_HZ/(1e6f*(prescale+1)));
 Wire.beginTransmission(PCA);Wire.write(uint8_t(6+4*i));Wire.write(0);Wire.write(0);Wire.write(count&255);Wire.write(count>>8);return Wire.endTransmission()==0;
}
void command(){
 if(ROLE_LEADER){
  if(!strcmp(line,"ZERO")){uint16_t raw[6];if(!sample(raw))return;memcpy(zeros,raw,sizeof zeros);prefs.putBytes("zeros",zeros,sizeof zeros);calibrated=true;Serial.println("ZERO saved at displayed home pose");return;}
  int j,sign,end=0;if(sscanf(line,"SIGN %d %d %n",&j,&sign,&end)==2&&line[end]==0&&j>=0&&j<6&&(sign==1||sign==-1)){signs[j]=sign;prefs.putBytes("signs",signs,sizeof signs);Serial.println("SIGN saved");return;}
  if(!strcmp(line,"FORGET")){prefs.remove("zeros");calibrated=false;Serial.println("RAW mode");return;}
  Serial.println("COMMANDS: ZERO | SIGN axis +/-1 | FORGET");return;
 }
 if(!strcmp(line,"STOP")){stop("user");return;}
 if(!strcmp(line,"ARM")){
  if(!FOLLOWER_CALIBRATED){stop("pulse_calibration_required");return;}
  if(!driverOK||!haveTarget||model::stale(millis(),lastTarget)){stop("fresh_home_target_required");return;}
  for(int i=0;i<6;i++)if(fabsf(goal[i]-model::home[i])>3){stop("home_pose_required");return;}
  memcpy(current,goal,sizeof goal);for(int i=0;i<6;i++)if(!servo(i,current[i])){stop("i2c_or_pulse_fault");return;}
  armed=true;digitalWrite(OE_PIN,LOW);Serial.println("ARMED");return;
 }
 float q[6];int end=0;
 if(sscanf(line,"Q %f %f %f %f %f %f %n",q,q+1,q+2,q+3,q+4,q+5,&end)==6&&line[end]==0&&model::valid(q)){
  for(int i=0;i<6;i++)if(!validPulse(i,q[i])){stop("pulse_limit");return;}
  memcpy(goal,q,sizeof q);lastTarget=millis();haveTarget=true;return;
 }
 stop("invalid_target");
}
void setup(){
 pinMode(OE_PIN,OUTPUT);digitalWrite(OE_PIN,HIGH);Serial.begin(115200);Wire.begin(SDA_PIN,SCL_PIN);Wire.setClock(100000);Wire.setTimeOut(20);
 memcpy(goal,model::home,sizeof goal);memcpy(current,goal,sizeof current);
 if(ROLE_LEADER){prefs.begin("thenar-L1",false);calibrated=prefs.getBytesLength("zeros")==sizeof zeros;if(calibrated)prefs.getBytes("zeros",zeros,sizeof zeros);if(prefs.getBytesLength("signs")==sizeof signs)prefs.getBytes("signs",signs,sizeof signs);for(int i=0;i<6;i++)if(signs[i]!=1&&signs[i]!=-1)signs[i]=1;}
 else {prescale=uint8_t(lroundf(PCA_CLOCK_HZ/(4096*50))-1);driverOK=writeReg(PCA,0,0x10)&&writeReg(PCA,0xFE,prescale)&&writeReg(PCA,1,4)&&writeReg(PCA,0,0x20);delay(5);}
 Serial.println(ROLE_LEADER?"THENAR AS5600 LEADER L1":"THENAR MG996R FOLLOWER R3 DISARMED");
}
void loop(){
 while(Serial.available()){
  char c=Serial.read();if(c=='\r')continue;
  if(c=='\n'){line[used]=0;if(overflow){if(ROLE_LEADER)Serial.println("FAULT line_overflow");else stop("line_overflow");}else if(used)command();used=0;overflow=false;}
  else if(used<sizeof line-1)line[used++]=c;else overflow=true;
 }
 uint32_t now=millis();if(!ROLE_LEADER&&armed&&model::stale(now,lastTarget))stop("watchdog");
 if(uint32_t(now-tick)<20)return;tick=now;
 if(ROLE_LEADER){
  uint16_t raw[6];if(!sample(raw))return;float q[6];for(int i=0;i<6;i++)q[i]=model::home[i]+signs[i]*model::wrappedDegrees(raw[i],zeros[i]);
  if(calibrated&&!model::valid(q)){Serial.println("FAULT joint_range");return;}
  Serial.print(calibrated?"L":"RAW");for(int i=0;i<6;i++){Serial.print(' ');if(calibrated)Serial.print(q[i],3);else Serial.print(raw[i]);}Serial.println();
 }else if(armed){for(int i=0;i<6;i++){current[i]=model::slew(current[i],goal[i]);if(!servo(i,current[i])){stop("i2c_or_pulse_fault");break;}}}
}

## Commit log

2026-09-18 Add original-derived MG996R follower and AS5600 encoder leader prototypes
    [688_bearing_front_L1.stl, 688_bearing_rear_L1.stl, AS5600_PCB_L1.stl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]
2026-09-18 Fix encoder report label initialization in viewer
    [main.js]
2026-09-23 Reconstruct SO-101 follower and leader in SolidWorks
    [688_bearing_front_L1.SLDPRT, 688_bearing_front_L1.STL, 688_bearing_front_L1_body0.SLDPRT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]
2026-09-23 Document SolidWorks assemblies and release in README
2026-09-24 Publish 3D assembly film and GitHub Pages site
2026-09-24 Add seekable assembly timeline
2026-09-24 Make 3D assembly loading resilient
2026-09-29 Publish Raspberry Pi wiring walkthrough
2026-09-29 Replace wiring film with one-ESP32 Pi-direct guide
2026-09-29 Publish large-print one-ESP wiring video
